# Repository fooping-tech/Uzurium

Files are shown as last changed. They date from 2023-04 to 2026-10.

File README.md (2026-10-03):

# Uzurium

Uzurium は、エモーショナルな渦を生成するオープンソースの装置です。
音楽・演劇・アートなどの表現活動において、独創的な演出を可能にすることを目指しています。

Uzurium_pic

## 特徴

- **オープンソース**：ソフトウェア・ハードウェアともに公開しており、自由に改良・再利用できます。
- **多彩な表現**：モータの回転と LED の光を組み合わせて、独自の渦を生み出せます。
- **作りやすさ**：シンプルな構造で、部品も入手しやすくなっています。
- **協調制御**：ESP-NOW で無線接続し、複数台の Uzurium を連携させられます。

## しくみ

DC モータで磁石を回し、瓶の中の回転子へ磁力で動力を伝えて渦を発生させます。
電源は、据え置きに便利な USB と、持ち運びに便利な電池の両方に対応しています。

内部構造

### 主な構成部品

- M5Atom（または M5Stamp）
- 制御基板（モータドライバ・昇圧電源・フォトリフレクタ・LED 18 灯を搭載）
- FA-130 モータ
- ネオジム磁石・回転子・瓶
- 電池ボックス
- 専用ケース（3D プリント）

## リポジトリ構成

```
Uzurium/
├── src/                      ファームウェア（Arduino スケッチ）
│   ├── Uzurium/              本体用（M5Atom）
│   ├── UzuriumController/    コントローラ用（M5Stack Core2）
│   └── UzuriumMaster/        マスター用（M5Stack Core2）
├── hardware/
│   ├── pcb/                  基板設計データ
│   │   ├── UzuriumCircuit_2/       最新基板：Gerber・BOM・レイアウト図・DXF
│   │   └── UzuriumBoard_v0.0.0/    初代基板：回路図・変更箇所
│   └── stl/                  3D プリント用データ
│       ├── common/           共通部品（プロペラ・モータブラケット等）
│       ├── case/             専用ケース
│       └── devkit/           DevKit 用部品
└── docs/
    └── BuildManual.md        DevKit 組立説明書
```

## ハードウェア

| 内容 | 場所 |
|---|---|
| 基板（最新） | [hardware/pcb/UzuriumCircuit_2](hardware/pcb/UzuriumCircuit_2) — Gerber・部品表・レイアウト図・外形 DXF |
| 基板（初代 v0.0.0） | [hardware/pcb/UzuriumBoard_v0.0.0](hardware/pcb/UzuriumBoard_v0.0.0) — 回路図と実装時の定数変更 |
| 3D プリント部品 | [hardware/stl](hardware/stl) |

## ビルドガイド

組み立て方法は [DevKit 組立説明書](docs/BuildManual.md) を参照してください。
はんだ付けなど、基本的な電子工作のスキルが必要です。

## ファームウェアの書き込み

Arduino IDE と M5Stack のボードマネージャがインストール済みであることを前提とします。

### 1. プロジェクトのダウンロード

```sh
git clone https://github.com/fooping-tech/Uzurium.git
```

または GitHub の「Code → Download ZIP」からダウンロードしてください。

### 2. ライブラリのインストール

Arduino IDE のライブラリマネージャから、使用するスケッチに応じて以下をインストールしてください。

| スケッチ | 対象デバイス | 必要なライブラリ |
|---|---|---|
| `src/Uzurium` | M5Atom | M5Atom, FastLED, arduinoFFT |
| `src/UzuriumController` | M5Stack Core2 | M5Unified, arduinoFFT, ArduinoTrace |
| `src/UzuriumMaster` | M5Stack Core2 | M5Core2 |

### 3. 書き込み

Uzurium 本体の場合は `src/Uzurium/Uzurium.ino` を Arduino IDE で開き、M5Atom に書き込みます。
コントローラ・マスターも同様に、各フォルダの `.ino` ファイルを開いて書き込んでください。

## ライセンス

Uzurium は MIT ライセンスで公開しています。詳細は [LICENSE](LICENSE) を参照してください。

## Third-party software

This firmware uses arduinoFFT.

- arduinoFFT version: 1.6.2
- License: GNU GPL v3
- Source: https://github.com/kosme/arduinoFFT

The source code corresponding to the firmware distributed with the device
is available in this repository.

## 作者

Uzurium は [@FoopingTech](https://github.com/fooping-tech) が開発しています。
ご意見・ご要望は Issues または Pull Request でお寄せください。

## 貢献方法

バグ報告、ドキュメントやコードの改善、新機能の追加など、Uzurium の改善・発展へのご協力を歓迎します。
詳細は [CONTRIBUTING.md](CONTRIBUTING.md) を参照してください。

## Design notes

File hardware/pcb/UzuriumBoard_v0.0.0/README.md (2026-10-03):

# Uzurium Board v0.0.0

初代 Uzurium 基板の回路図です。

- [SCH_UzuriumCircuit_2023-08-30.pdf](SCH_UzuriumCircuit_2023-08-30.pdf)

## 回路図からの変更箇所

v0.0.0 基板では、回路図の定数から以下の部品を変更して実装してください。

### フォトセンサ感度変更
- RPH1: 220Ω → 110Ω
- RPH2: 1kΩ → 10kΩ

### 昇圧電源 FB 電圧変更
- RP1: 1.37kΩ → 10kΩ
- RP2: 10kΩ → 1.37kΩ

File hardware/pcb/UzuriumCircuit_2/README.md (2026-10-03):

# UzuriumCircuit_2

Uzurium 制御基板（UzuriumCircuit_2）の設計データです。EasyEDA で設計しています（2026-10-04 出力）。

## ファイル

| ファイル | 内容 |
|---|---|
| [Gerber_PCB_UzuriumCircuit_2_2026-10-04.zip](Gerber_PCB_UzuriumCircuit_2_2026-10-04.zip) | 基板製造用 Gerber / ドリルデータ |
| [BOM_UzuriumCircuit_UzuriumCircuit_2026-10-04.csv](BOM_UzuriumCircuit_UzuriumCircuit_2026-10-04.csv) | 部品表（UTF-16・タブ区切り、EasyEDA 出力形式） |
| [PCB_PCB_UzuriumCircuit_2_2026-10-04.pdf](PCB_PCB_UzuriumCircuit_2_2026-10-04.pdf) | 基板レイアウト図 |
| [DXF_PCB_UzuriumCircuit_2_2026-10-04.dxf](DXF_PCB_UzuriumCircuit_2_2026-10-04.dxf) | 基板外形 DXF（ケース設計用） |

## 基板の発注

Gerber の zip ファイルをそのまま JLCPCB などの基板製造サービスにアップロードしてください。
発注手順は [EasyEDA のドキュメント](https://prodocs.easyeda.com/en/pcb/order-order-pcb/index.html) を参照してください。

## 部品表（BOM）

LCSC 列は LCSC / JLCPCB の部品番号です。

| No. | 数量 | 部品 | リファレンス | フットプリント | メーカー型番 | メーカー | LCSC |
|---|---|---|---|---|---|---|---|
| 1 | 9 | 100nF | C13, CA1, CM1, CM2, CM3, CM5, CM6, CPH1, CS1 | C0603 | CL10B104KC8NNNC | SAMSUNG(三星) | C15725 |
| 2 | 1 | 270uF | CM4 | CAP-SMD_BD10.0-L10.3-W10.3-FD | EEHZA1V271P | PANASONIC(松下) | C79124 |
| 3 | 1 | B3B-XH-AM-(LF)(SN) | CNA1 | CONN-TH_3P-P2.50_B3B-XH-AM-LF-SN | B3B-XH-AM(LF)(SN) | JST | C161870 |
| 4 | 2 | B2B-XH-A-M_C2858045 | CNB1, CNM1 | CONN-TH_2P-P2.50_JST_B2B-XH-A-M_C2858045 | B2B-XH-A-M | JST | C2858045 |
| 5 | 1 | M5 ATOM PCB Connector | CNM5 | M5ATOM |  |  | M5-ATOM-PCB-CONN |
| 6 | 2 | 22uF | CP1, CP2 | 0805 | GRM21BR60J226ME39L | MuRata | C77071 |
| 7 | 1 | B0520LW | DP1 | SOD-123 | B0520LW | STARSEA | C89640 |
| 8 | 1 | 1SMA4734A_C438355 | DP2 | SMA_L4.3-W2.5-LS5.0-RD | 1SMA4734A | 晶导微电子 | C438355 |
| 9 | 1 | DRV8839DSSR | ICM1 | WSON-12_L3.0-W2.0-P0.50-BL-EP | DRV8839DSSR | TI(德州仪器) | C128627 |
| 10 | 1 | SX1308 | ICP1 | SOT-23-6 | SX1308 | SX | C78162 |
| 11 | 1 | LBR-127HLD | ICPH1 | LBR-127HLD | RPR-220 | ROHM(罗姆) | C21062 |
| 12 | 1 | TC7S14FU,LF | ICPH2 | SOT-353-5_L2.0-W2.1-P0.65-BR | TC7S14FU,LF | TOSHIBA(东芝) | C7032 |
| 13 | 18 | WS2812B-XF02/W | LED1〜LED18 | LED-SMD_4P-L5.0-W5.0-TL | WS2812B-XF02/W | worldsemi | C4154882 |
| 14 | 1 | 4.7uH | LP1 | 5040 | SWPA5040S4R7MT | Sunlord | C48496 |
| 15 | 8 | 1kΩ | RM1, RM2, RM3, RPH2, RPH3, RPH4, RS1, RS2 | R0603 | WR06X102JTL | Walsin(华新科) | C384295 |
| 16 | 1 | 1.37kΩ | RP1 | R0805 | RTT051371FTP | RALEC(旺诠) | C103980 |
| 17 | 1 | 10kΩ | RP2 | R0805 | RTT051002FTP | RALEC(旺诠) | C103904 |
| 18 | 1 | 220 | RPH1 | R0603 | RC0603JR-07220RL | YAGEO(国巨) | C114683 |
| 19 | 1 | SK-22F03-G060 | SWB1 | SW-TH_G-SWITCH_SK-22F03-G060 | SK-22F03-G060 | G-Switch(品赞) | C2848866 |
| 20 | 1 | PS-5850DHA-3PNA | SWS1 | SW-TH_G-SWITCH_PS-585XX | PS-5850DHA-3PNA | G-Switch(品赞) | C5155592 |
| 21 | 3 | 5004 | TP33, TP50, TPBAT1 | TEST-TH_BD2.54-P1.39 | 5004 | Keystone | C2906762 |
| 22 | 1 | 5001 | TPGND1 | TEST-TH_BD2.54-P1.39 | 5001 | Keystone | C238122 |

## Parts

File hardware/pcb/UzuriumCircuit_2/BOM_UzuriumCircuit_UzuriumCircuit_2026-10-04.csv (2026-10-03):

No. | Quantity | Comment | Designator | Footprint | Value | Manufacturer Part | Manufacturer | Supplier Part | Supplier
1 | 9 | 100nF | C13,CA1,CM1,CM2,CM3,CM5,CM6,CPH1,CS1 | C0603 |  | CL10B104KC8NNNC | SAMSUNG(三星) | C15725 | LCSC
2 | 1 | 270uF | CM4 | CAP-SMD_BD10.0-L10.3-W10.3-FD |  | EEHZA1V271P | PANASONIC(松下) | C79124 | LCSC
3 | 1 | B3B-XH-AM-(LF)(SN) | CNA1 | CONN-TH_3P-P2.50_B3B-XH-AM-LF-SN |  | B3B-XH-AM(LF)(SN) | JST | C161870 | LCSC
4 | 2 | B2B-XH-A-M_C2858045 | CNB1,CNM1 | CONN-TH_2P-P2.50_JST_B2B-XH-A-M_C2858045 |  | B2B-XH-A-M | JST | C2858045 | LCSC
5 | 1 | M5 ATOM PCB Connector | CNM5 | M5ATOM |  |  |  | M5-ATOM-PCB-CONN
6 | 2 | 22uF | CP1,CP2 | 0805 |  | GRM21BR60J226ME39L | MuRata | C77071 | LCSC
7 | 1 | B0520LW | DP1 | SOD-123 |  | B0520LW | STARSEA | C89640 | LCSC
8 | 1 | 1SMA4734A_C438355 | DP2 | SMA_L4.3-W2.5-LS5.0-RD |  | 1SMA4734A | 晶导微电子 | C438355 | LCSC
9 | 1 | DRV8839DSSR | ICM1 | WSON-12_L3.0-W2.0-P0.50-BL-EP |  | DRV8839DSSR | TI(德州仪器) | C128627 | LCSC
10 | 1 | SX1308 | ICP1 | SOT-23-6 |  | SX1308 | SX | C78162 | LCSC
11 | 1 | LBR-127HLD | ICPH1 | LBR-127HLD |  | RPR-220 | ROHM(罗姆) | C21062 | LCSC
12 | 1 | TC7S14FU,LF | ICPH2 | SOT-353-5_L2.0-W2.1-P0.65-BR |  | TC7S14FU,LF | TOSHIBA(东芝) | C7032 | LCSC
13 | 18 | WS2812B-XF02/W | LED1,LED2,LED3,LED4,LED5,LED6,LED7,LED8,LED9,LED10,LED11,LED12,LED13,LED14,LED15,LED16,LED17,LED18 | LED-SMD_4P-L5.0-W5.0-TL |  | WS2812B-XF02/W | worldsemi | C4154882 | LCSC
14 | 1 | 4.7uH | LP1 | 5040 |  | SWPA5040S4R7MT | Sunlord | C48496 | LCSC
15 | 8 | 1kΩ | RM1,RM2,RM3,RPH2,RPH3,RPH4,RS1,RS2 | R0603 |  | WR06X102JTL | Walsin(华新科) | C384295 | LCSC
16 | 1 | 1.37kΩ | RP1 | R0805 |  | RTT051371FTP | RALEC(旺诠) | C103980 | LCSC
17 | 1 | 10kΩ | RP2 | R0805 |  | RTT051002FTP | RALEC(旺诠) | C103904 | LCSC
18 | 1 | 220 | RPH1 | R0603 |  | RC0603JR-07220RL | YAGEO(国巨) | C114683 | LCSC
19 | 1 | SK-22F03-G060 | SWB1 | SW-TH_G-SWITCH_SK-22F03-G060 |  | SK-22F03-G060 | G-Switch(品赞) | C2848866 | LCSC
20 | 1 | PS-5850DHA-3PNA | SWS1 | SW-TH_G-SWITCH_PS-585XX |  | PS-5850DHA-3PNA | G-Switch(品赞) | C5155592 | LCSC
21 | 3 | 5004 | TP33,TP50,TPBAT1 | TEST-TH_BD2.54-P1.39 |  | 5004 | Keystone | C2906762 | LCSC
22 | 1 | 5001 | TPGND1 | TEST-TH_BD2.54-P1.39 |  | 5001 | Keystone | C238122 | LCSC

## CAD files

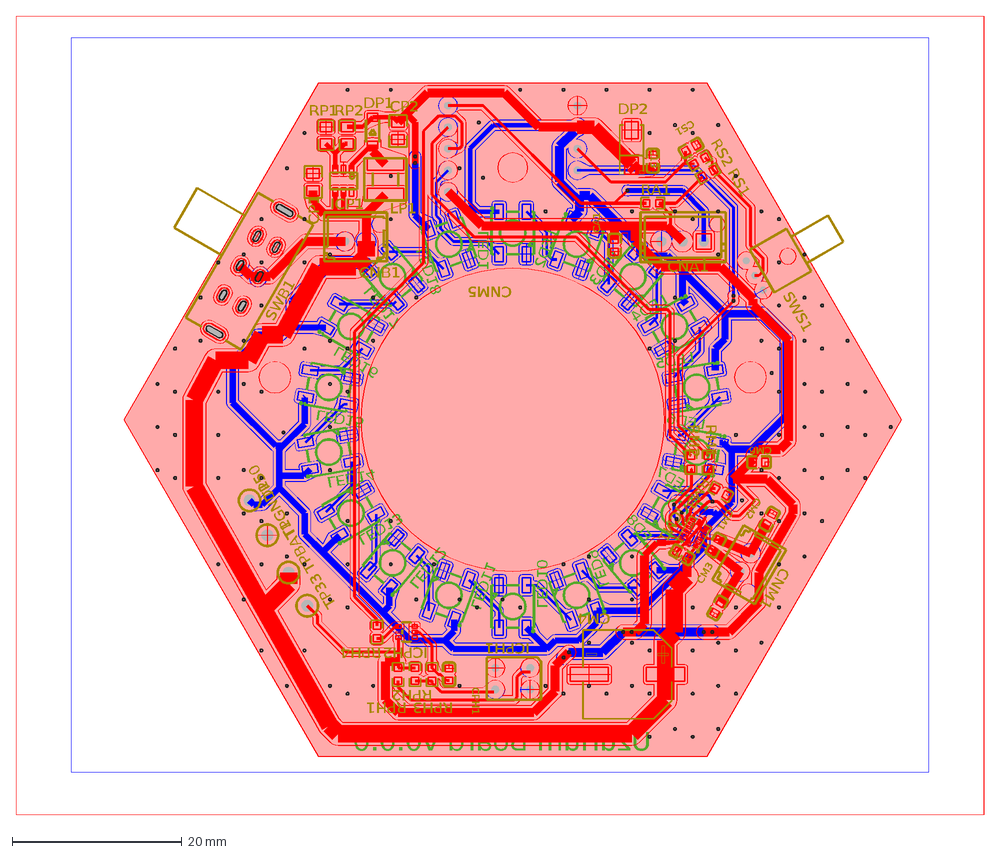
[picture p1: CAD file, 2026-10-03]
hardware/pcb/UzuriumCircuit_2/DXF_PCB_UzuriumCircuit_2_2026-10-04.dxf
Uzurium Board v0.0.0
LED1
LED2
LED3
LED4
LED5
LED6
LED7
LED8
LED9
LED10
LED11
LED12
LED13
LED14
LED15
LED16
LED17
LED18
TPGND1
TP33
TP50
CM4
CNA1
CNB1
CNM1
CNM5
CP1
CP2
DP1
DP2
ICM1
ICP1
ICPH1
ICPH2
LP1
RA1
RM1
RM2
RM3
RP1
RP2
RPH1
RPH2
RPH3
RPH4
RS1
RS2
SWB1
SWS1
TPBAT1
CM2
CM3
CM5
CM6
CPH1
CA1
CS1
CM1
C13

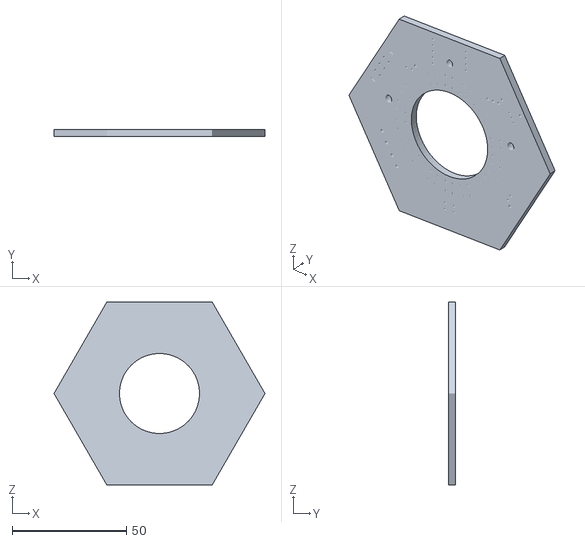
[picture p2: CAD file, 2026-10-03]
hardware/stl/case/cap.stl
92.3 x 2.90 x 80.0

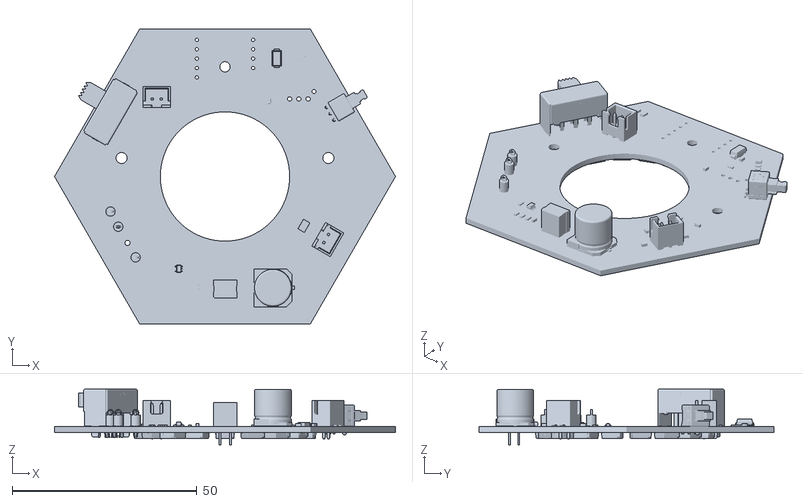
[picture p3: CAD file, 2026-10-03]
hardware/stl/common/3D_PCB_UzuriumCircuit_v.0.0.0.stl
92.3 x 80.0 x 15.1

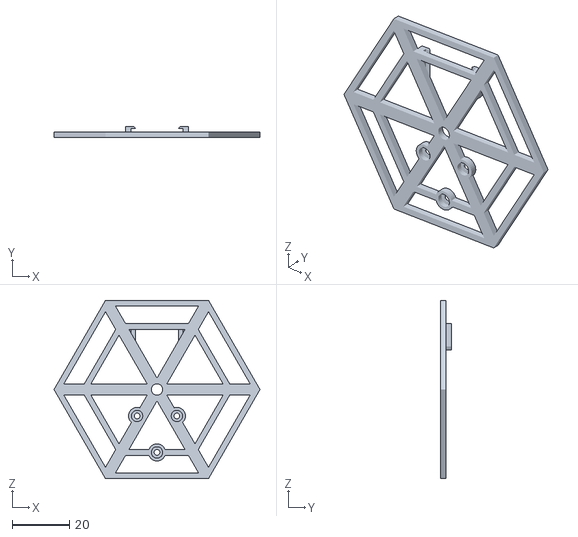
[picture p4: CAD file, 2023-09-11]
hardware/stl/devkit/bottom.stl
72.0 x 4.00 x 62.4

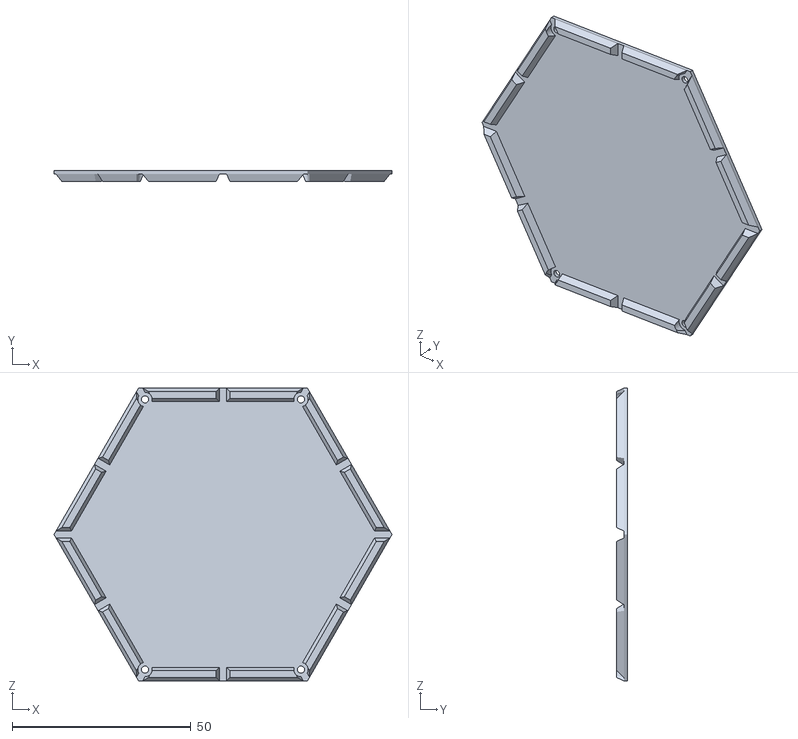
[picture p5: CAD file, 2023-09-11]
hardware/stl/case/bottom.stl
94.7 x 3.00 x 82.0

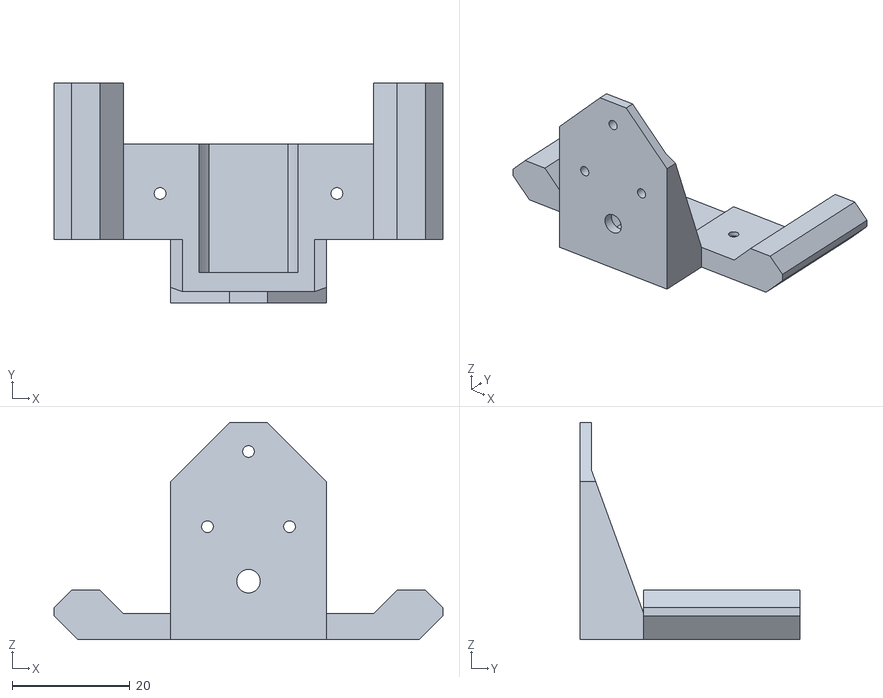
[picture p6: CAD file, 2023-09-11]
hardware/stl/common/MotorBraket.stl
66.0 x 37.4 x 36.8

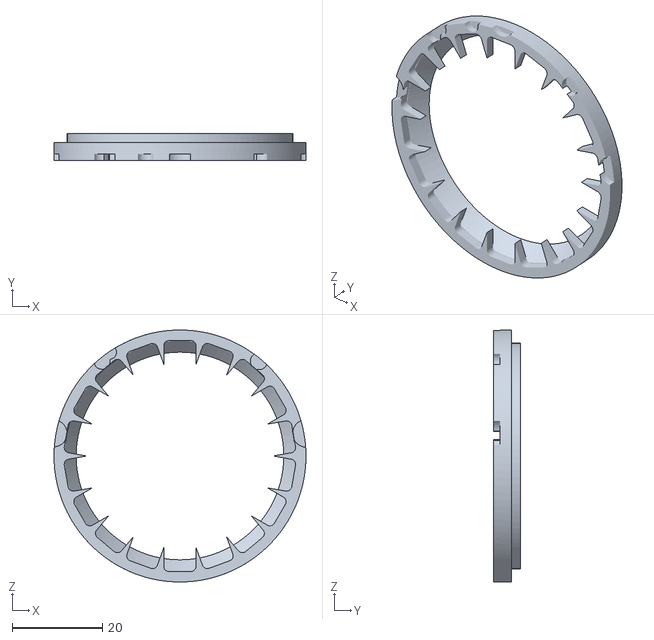
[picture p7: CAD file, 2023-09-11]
hardware/stl/devkit/CAP2.stl
55.8 x 5.90 x 55.8

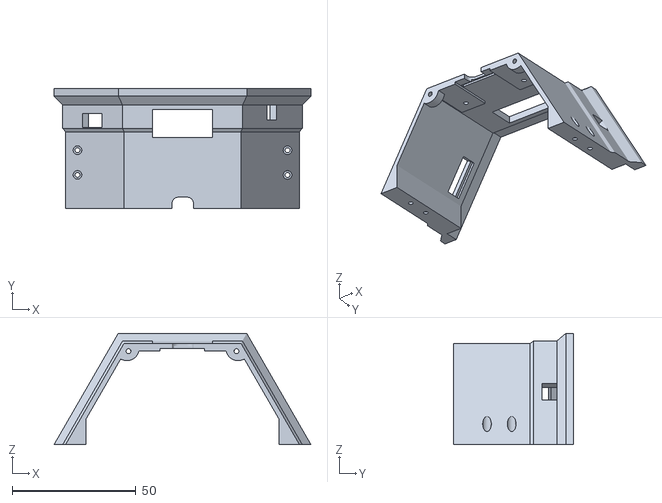
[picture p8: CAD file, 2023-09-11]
hardware/stl/case/CASE_ushiro.stl
104.0 x 48.4 x 45.0

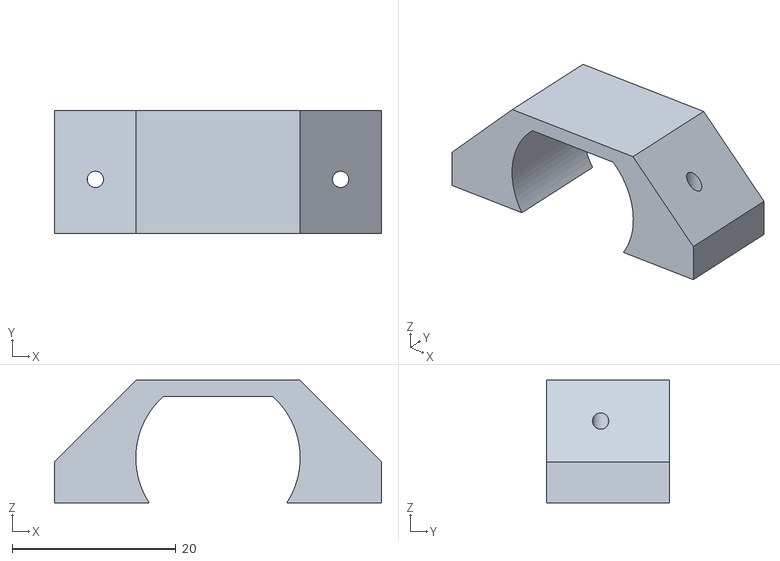
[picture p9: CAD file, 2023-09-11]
hardware/stl/common/MotorCover.stl
40.0 x 15.0 x 15.0

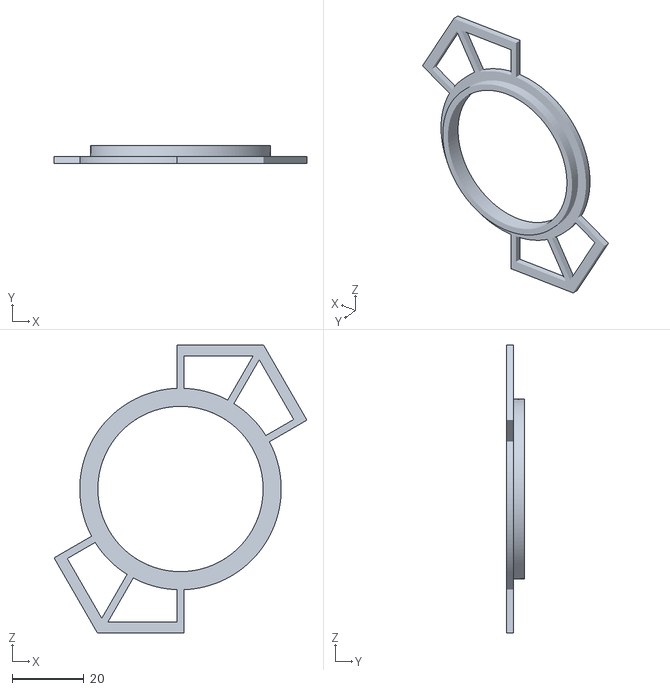
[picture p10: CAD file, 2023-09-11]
hardware/stl/case/top.stl
70.4 x 5.00 x 80.2

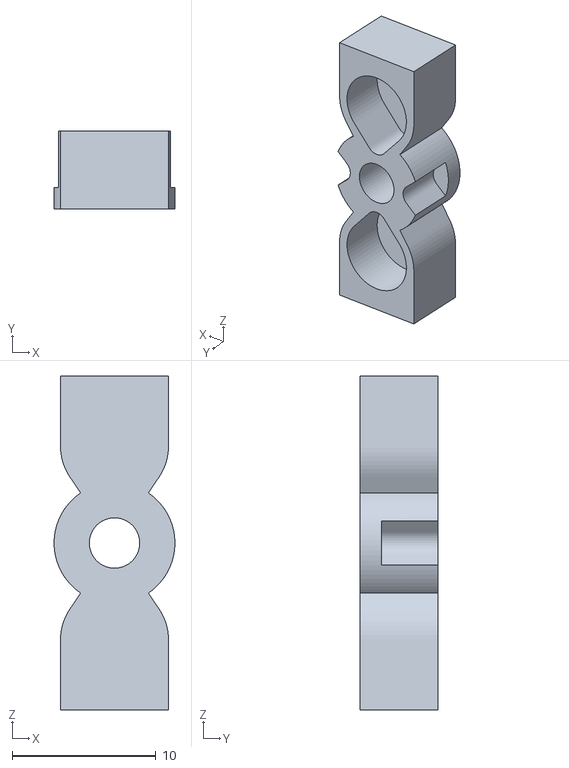
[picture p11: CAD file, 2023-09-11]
hardware/stl/common/propeller.stl
8.39 x 5.40 x 23.2

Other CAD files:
hardware/stl/case/CASE_mae.stl

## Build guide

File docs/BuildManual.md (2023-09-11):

# Uzurium DevKit 組立説明書

## 完成イメージ





## 部品リスト

部品一覧

| No. | 部品名称 | 個数 | イメージ |
|---|---|---|---|
| 1 | プロペラ・ネオジム磁石x2・反射シール | 1set | スクリーンショット 2023-09-09 0 05 23 |
| 2 | モータワイヤ | 1 |スクリーンショット 2023-09-09 0 06 24|
| 3 | モータ | 1 |スクリーンショット 2023-09-09 0 06 35|
| 4 | モータカバー | 1 |スクリーンショット 2023-09-09 0 06 44|
| 5 | モータステー | 1 | スクリーンショット 2023-09-09 0 06 55|
| 6 | ネジ | 1set | スクリーンショット 2023-09-09 0 07 06|
| 7 | NEO PIXEL LED | 1set | スクリーンショット 2023-09-09 0 07 15|
| 8 | USB充電基板 | 1 |スクリーンショット 2023-09-09 0 12 56|
| 9 | 電源ワイヤ | 1 |スクリーンショット 2023-09-09 0 13 59|
| 10 | ピンヘッダ | 1 |スクリーンショット 2023-09-09 0 15 52|
| 11 | フォトセンサ | 1 |スクリーンショット 2023-09-09 0 16 08|
| 12 | Uzurium基板 | 1 |スクリーンショット 2023-09-09 0 16 21|
| 13 | トップカバー | 1 |スクリーンショット 2023-09-09 0 16 40|
| 14 | ボトムプレート | 1 |スクリーンショット 2023-09-09 0 16 56|
| 15 | 回転子 | 1 |スクリーンショット 2023-09-09 0 17 19|
| 16 | 拡張キット | 1set |スクリーンショット 2023-09-09 0 17 35|

## 必要なもの
- プラスドライバー
- ラジオペンチ
- はんだごて・はんだ

## 組み立て方
### モータとモータワイヤを半田付けする



### モータをモータカバーとモータステー、M2ネジ6mmx2で固定する


### プロペラに反射シールを貼る
### プロペラにネオジム磁石を押し込む(硬い場合はラジオペンチで挟み押し込む)
### モータ付属のゴムチューブを5mm程度にカットしプロペラの中央穴に裏面から差し込む


### プロペラをモータの軸に差し込む


### Uzurium基板にピンヘッダを半田付けする


### Uzurium基板にフォトセンサを半田付けする
RPH1を100Ωへ変更する


### Uzurium基板にNEO PIXEL LEDを半田付けする


### USB充電基板に電源ワイヤを半田付けする


### ボトムプレートにUSB充電基板を固定する


### モータステーとボトムプレートをM2ネジ4mm x3で固定する


### Uzurium基板とモータステーをM2ネジ6mm x2で固定する


### トッププレートを被せる


### 電源ワイヤをUzurium基板のCNB1コネクタに差し込む


### モータワイヤをUzurium基板のCNM1コネクタに差し込む


### M5ATOMをピンヘッダに差し込む

### Uzurium DevKit完成！

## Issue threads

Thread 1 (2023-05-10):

時報機能のための基本的な関数の提供について

fooping-tech, 2023-05-10:
## 概要
Uzuriumには、時報機能が必要です。この機能を組み込むために、開発者が利用できる基本的な関数を提供したいと考えています。

## 要件
- 開発者は、現在の時刻を取得するための関数を利用できる必要があります。
- 開発者は、時刻を設定するためにインターネット関数を利用できる必要があります。
- 開発者は、タイマーを開始し、経過時間を取得するための関数を利用できる必要があります。
- 開発者は、タイマーを停止するための関数を利用できる必要があります。
- 開発者は、現在の日付を取得するための関数を利用できる必要があります。
- 開発者は、NTPサーバーからの現在時刻取得機能を利用できる必要があります

fooping-tech, 2023-12-05:
ntpブランチにて実装中
https://github.com/fooping-tech/Uzurium/tree/feature/ntp

fooping-tech, 2023-12-05:
mainにマージ

Closed 2023-12-05.

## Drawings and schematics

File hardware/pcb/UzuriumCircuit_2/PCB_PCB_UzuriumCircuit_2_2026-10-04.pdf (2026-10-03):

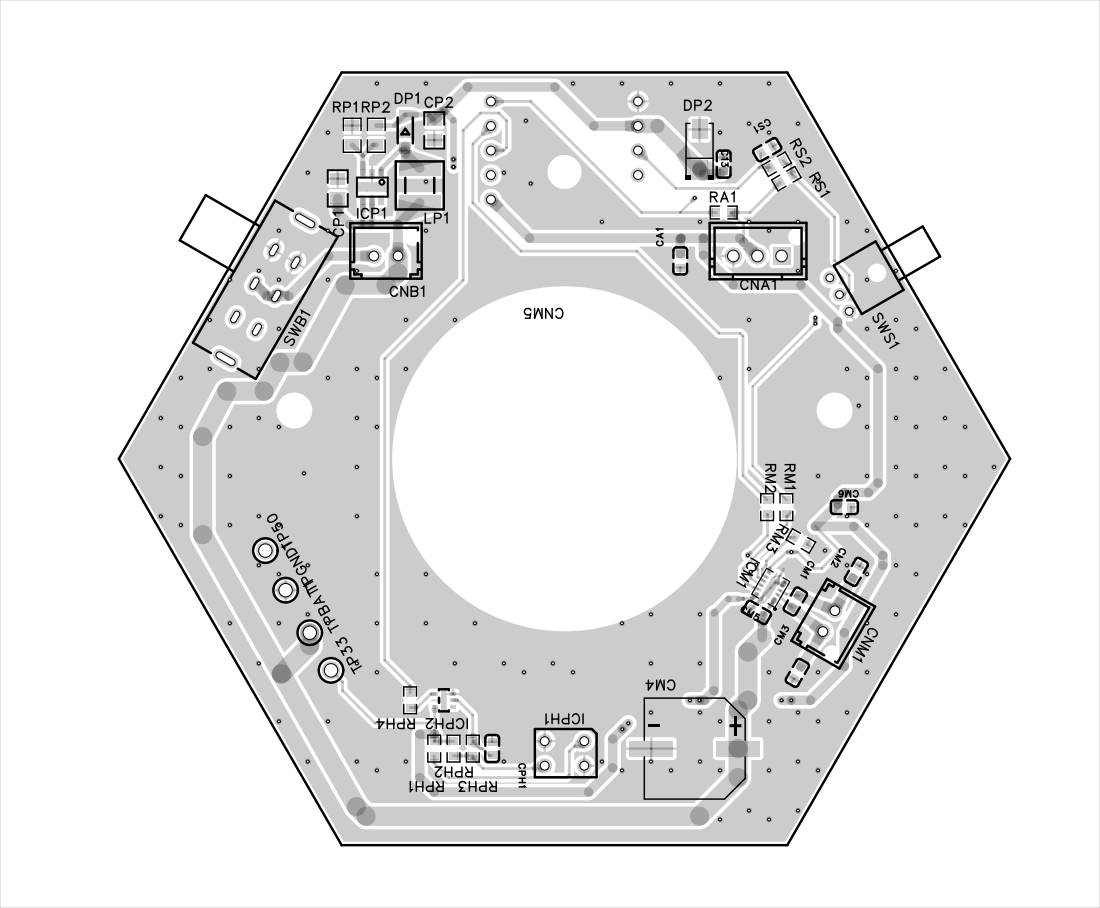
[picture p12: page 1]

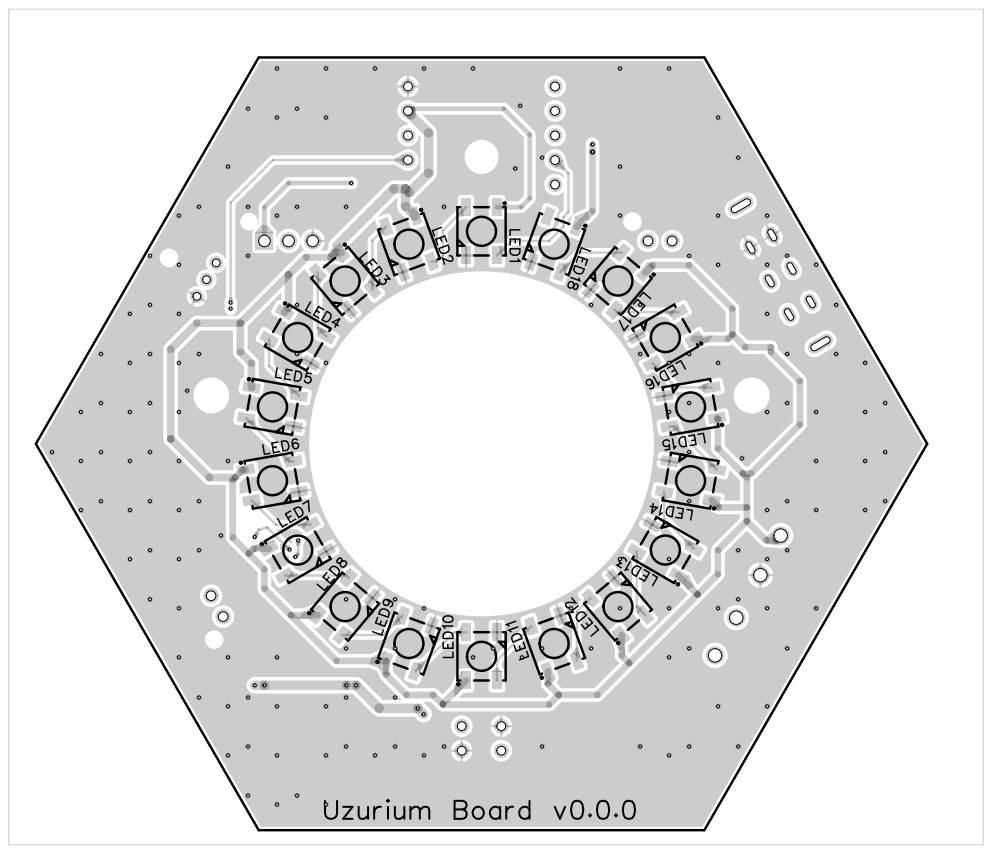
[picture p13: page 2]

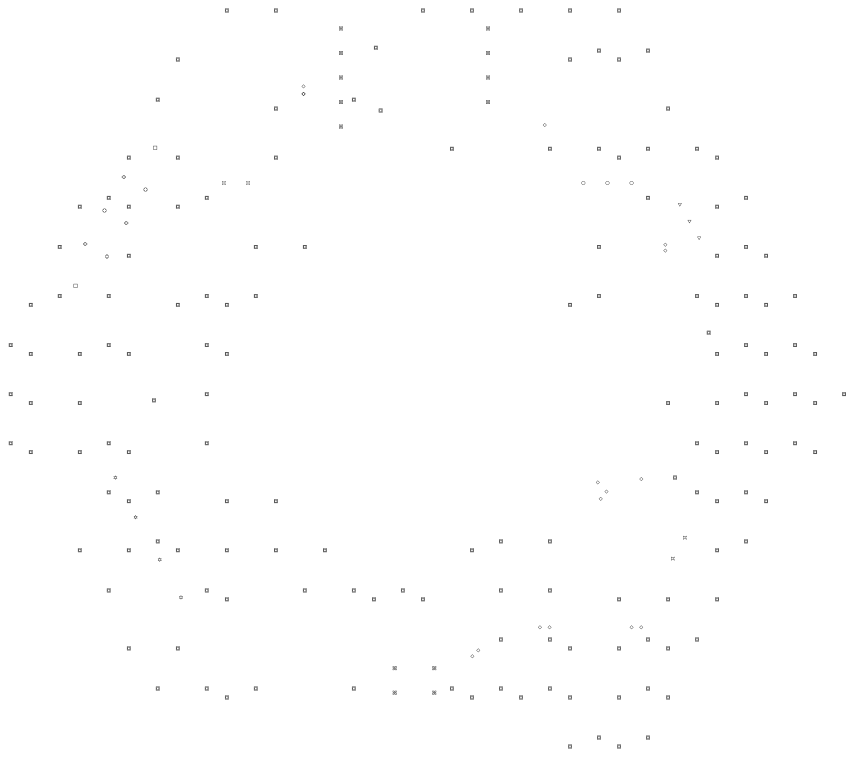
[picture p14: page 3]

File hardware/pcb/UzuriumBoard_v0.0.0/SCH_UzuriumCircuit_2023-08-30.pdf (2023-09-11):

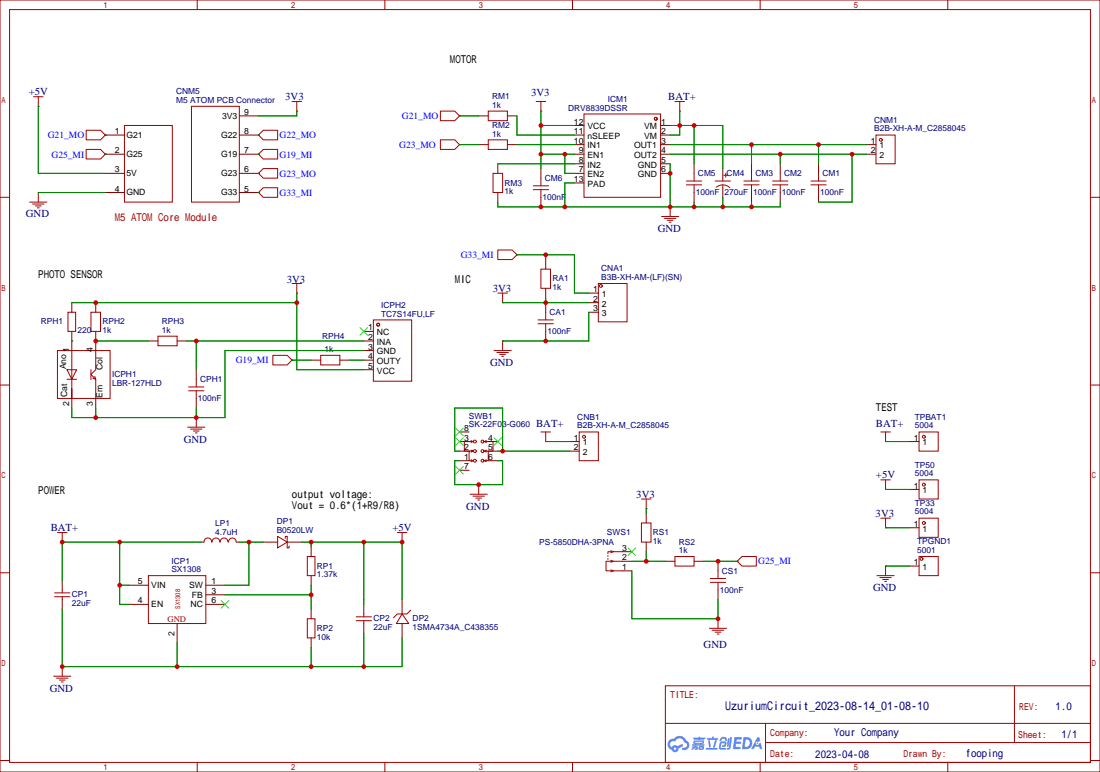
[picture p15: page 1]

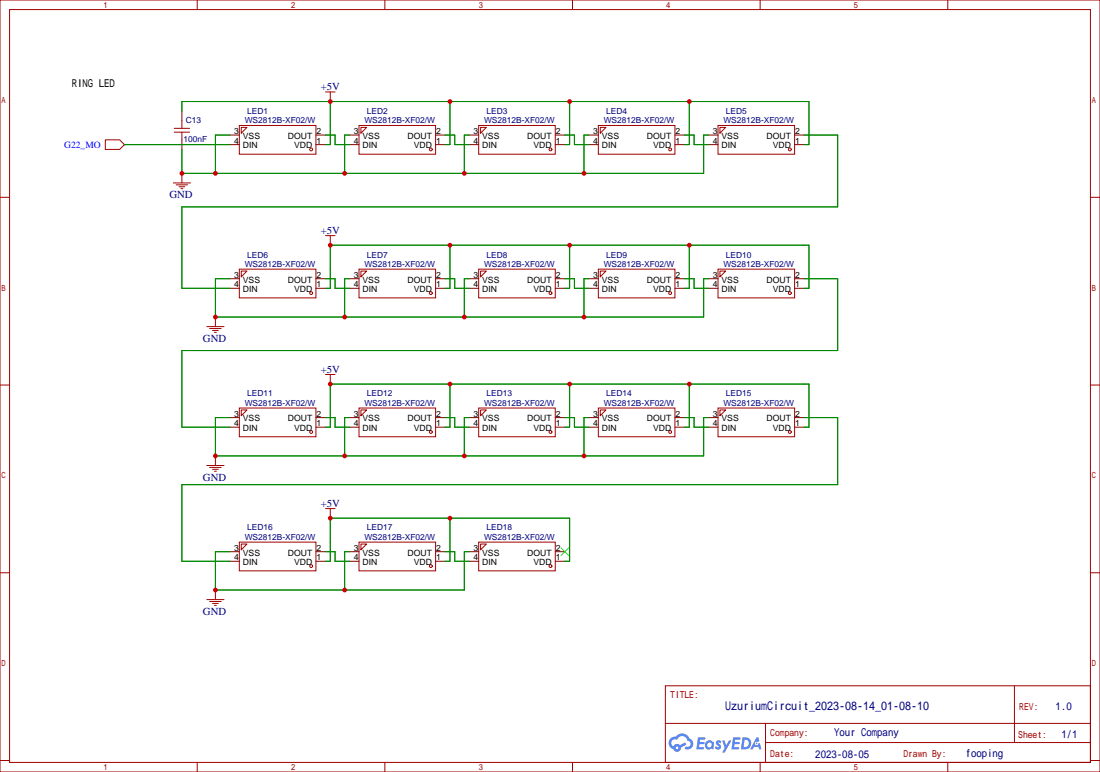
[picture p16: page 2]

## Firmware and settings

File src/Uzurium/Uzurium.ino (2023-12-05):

#include "./configuration.h"
#if __has_include("Setting.h")
#include "./Setting.h"
#else
#define WIFI_SSID "your_ssid"
#define WIFI_PASS "your_password"
#endif
DCMPWM motor = DCMPWM();
RINGLED led = RINGLED();
PHOTO photo = PHOTO();
SW switch1 = SW(SW_PIN,INPUT);
SW switch2 = SW(TEST_SW_PIN,INPUT_PULLUP);

// モードオブジェクトのポインタ
MODE *currentMode;

// WiFiの接続処理
void initWiFi() {
  WiFi.mode(WIFI_STA);
  Serial.print("\nConnecting to " WIFI_SSID);
  WiFi.begin(WIFI_SSID, WIFI_PASS);     // WiFiに接続
  int i = 1;
  while (WiFi.status() != WL_CONNECTED) { // WiFiが繋がるまでループ
    if (i > 20) {                       // 10秒のタイムアウト
      Serial.println("\n========== WiFi connecting timeout! ==========\n");
      //ESP.restart();                    // リセット
      break;
    }
    delay(500);                         // 500ミリ秒待つ
    Serial.print(".");                  // ログに「.」を表示
    i++;
  }
  Serial.println("\nWiFi connected");   // ログに「WiFi connected」を表示
  Serial.print("IP address: ");         // ログにIPアドレスを表示
  Serial.println(WiFi.localIP());
}

void setup() {
  //M5 INITIAL

  M5.begin(true, false, true); 
  //MOTOR INITIAL
  motor.setup(CHANNEL,MOTOR_PIN);
  photo.setup(PHOTO_PIN);
  
  //MOTOR SLEEP
  // pinMode(21, OUTPUT);
  // digitalWrite(21, HIGH);

  //LED_INITIAL
  led.setup(LED_PIN);//led setup (led_num)

  //ESP-NOW INITIAL
  ESPNOW_setup();
  initWiFi();                           // WiFiの接続処理
  // NTPの初期化
  configTzTime("JST-9", "ntp.nict.jp"); 
  //timeInfo.tm_year + 1900 //timeInfo.tm_mon + 1 //timeInfo.tm_mday //timeInfo.tm_hour //timeInfo.tm_min //timeInfo.tm_sec

  //初期モードにセット
  if(switch2.check_a()==1){
    currentMode = new StopMode(&photo,&motor,&led);
  }
  else{
    currentMode = new TestMode(&photo,&motor,&led);
  }
  //Core0でタスク起動
  xTaskCreatePinnedToCore(
    Uzurium_Task        // タスク関数へのポインタ。無限ループで終了しないよう関数を指定します
    ,  "TaskMotion"   // タスクの説明用名前。重複しても動きますがデバッグ用途。最大16文字まで
    ,  4096  //スタックサイズ(Byte)
    ,  NULL //作成タスクのパラメータのポインタ
    ,  2  // Priority, with 3 (configMAX_PRIORITIES - 1) being the highest, and 0 being the lowest..  优先级，3 (configMAX_PRIORITIES - 1) 最高，0 最低。
    ,  NULL //作成タスクのHandleへのポインタ
    ,  0);  //利用するCPUコア(0-1)
}

void Uzurium_Task(void *pvParameters){
  while(1){
    Uzurium_main();
    delay(1);
  }
}

void Uzurium_Ntp(){
  struct tm timeInfo;
  getLocalTime(&timeInfo);
  if(timeInfo.tm_sec == 0 && currentMode->name == "StopMode"){
    delete currentMode;
    currentMode = new TimerMode(&photo,&motor,&led);
  }
}

void Uzurium_CheckSW(){
  //スイッチ(モーメンタリ)
  int sw = switch1.check_m();
  //スイッチ(オルタネート)
  int sw2= switch2.check_a();
  //前回値からの変更有無
  bool sw2st = switch2.check_change();
  //TEST_SWが前回値から変更されていたらsw2の論理にあわせたモードへ変更
  if(sw2st){
      if(sw2==0){
        delete currentMode;
        currentMode = new TestMode(&photo,&motor,&led);
      }
      else{
        delete currentMode;
        currentMode = new StopMode(&photo,&motor,&led);
      }
  }

  if(sw2==1){//オルタネートSW = OFF
    // ダブル:3 ,長押し:2,短押し:1,押していない:0
    if(sw==1){
      if(currentMode->name != "StopMode"){
        delete currentMode;
        currentMode = new StopMode(&photo,&motor,&led);
      }else{
        delete currentMode;
        currentMode = new ADinputMode(&photo,&motor,&led);
      }
    }
    if(sw==2){
        delete currentMode;
        currentMode = new FeedBackMode(&photo,&motor,&led);
    }
    if(sw==3){
        delete currentMode;
        currentMode = new TimerMode(&photo,&motor,&led);
    }



    //M5AtomSWプッシュ時の動作
    if(M5.Btn.wasPressed()){
        if(currentMode->name=="StopMode"){
          delete currentMode;
          currentMode = new ADinputMode(&photo,&motor,&led);
        }else 
        if(currentMode->name=="ADinputMode"){
          delete currentMode;
          currentMode = new FeedBackMode(&photo,&motor,&led);
        }else 
        if(currentMode->name=="FeedBackMode"){
          delete currentMode;
          currentMode = new TimerMode(&photo,&motor,&led);
        }else
        if(currentMode->name=="TimerMode"){
          delete currentMode;
          currentMode = new StopMode(&photo,&motor,&led);
        }

    }
 
  }else{//オルタネートSW = ON
    // ダブル:3 ,長押し:2,短押し:1,押していない:0
    if(sw==1){
      if(currentMode->name != "TestMode"){
        delete currentMode;
        currentMode = new TestMode(&photo,&motor,&led);
      }else{
        delete currentMode;
        currentMode = new ADInspectionMode(&photo,&motor,&led);
      }
    }
    if(sw==2){
        delete currentMode;
        currentMode = new PhotoReflectorInspectionMode(&photo,&motor,&led);
    }
    if(sw==3){
        delete currentMode;
        currentMode = new LedInspectionMode(&photo,&motor,&led);
      
    }

    if(M5.Btn.wasPressed()){
        if(currentMode->name=="TestMode"){
          delete currentMode;
          currentMode = new ADInspectionMode(&photo,&motor,&led);
        }else 
        if(currentMode->name=="ADInspectionMode"){
          delete currentMode;
          currentMode = new PhotoReflectorInspectionMode(&photo,&motor,&led);
        }else 
        if(currentMode->name=="PhotoReflectorInspectionMode"){
          delete currentMode;
          currentMode = new TestMode(&photo,&motor,&led);
        }
    }
  }
}

void Uzurium_main(){

// 現在のモードのmainloop()を呼び出す
  currentMode->mainloop();
  currentMode->SetAdValue(FFT_CheckADvalue());

  //現在の実行モードが非アクティブになった場合はStopModeへ入れる
  if(currentMode->active==false){
    delete currentMode;
    currentMode = new StopMode(&photo,&motor,&led);
  }
  
  //RemoteControlModeのときはESPNOW受信値をパラメータにセットする
  if(currentMode->name=="RemoteControlMode"){
    currentMode->SetParams(ESPNOW_CheckDuty(),ESPNOW_CheckHue(),ESPNOW_CheckBrightness());
  }
  //ADInspectionModeのときにUzurium_Numberを設定する
  if(currentMode->name=="ADInspectionMode"){
        Uzurium_Number =  map(FFT_CheckADvalue(),0,4095,1,18);
  }

}

void loop() {
  M5.update();
  //Analog pin読み取り
  FFT_main();
  //スイッチ状態チェック
  Uzurium_CheckSW();
  //Ntpチェック
  if(WiFi.status() == WL_CONNECTED){
    Uzurium_Ntp();
  }
}

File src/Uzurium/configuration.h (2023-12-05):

#ifndef CONFIGURATION_H
#define CONFIGURATION_H

//#include <M5Unified.h>
#include <M5Atom.h>
#include <esp_now.h>
#include <WiFi.h>
#include <Wire.h>

#include "DCMPWM.h"
#include "RINGLED.h"
#include "PHOTO.h"
#include "MODE.h"
#include "SW.h"

//motor pin setting
#define MOTOR_PIN 23

//motor PWM CH(for MotorDrive)
#define CHANNEL 2

//led pin setting
#define LED_PIN 22

//PhotoSensor pin setting
#define PHOTO_PIN 19

//Analog pin setting
#define ANALOG_PIN 33

//SW setting モーメンタリ
#define SW_PIN 25

//SW setting オルタネート
#define TEST_SW_PIN 21

int Uzurium_Number = 0;




#endif

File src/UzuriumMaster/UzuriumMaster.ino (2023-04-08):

#include <esp_now.h>
#include <WiFi.h>
#include <esp_wifi.h> // only for esp_wifi_set_channel()
#include <M5Core2.h>

// Defines gestures
Gesture swipeRight("swipe right", 160, DIR_RIGHT, 30, true);
Gesture swipeDown("swipe down", 120, DIR_DOWN, 30, true);
Gesture swipeLeft("swipe left", 160, DIR_LEFT, 30, true);
Gesture swipeUp("swipe up", 120, DIR_UP, 30, true);

// Defines the buttons. Colors in format {bg, text, outline}
ButtonColors on_clrs = {RED, WHITE, WHITE};
ButtonColors off_clrs = {BLACK, WHITE, WHITE};
Button tl(0, 0, 0, 0, false ,"top-left", off_clrs, on_clrs, TL_DATUM);
Button bl(0, 0, 0, 0, false, "bottom-left", off_clrs, on_clrs, BL_DATUM);
Button tr(0, 0, 0, 0, false, "top-right", off_clrs, on_clrs, TR_DATUM);
Button br(0, 0, 0, 0, false, "bottom-right", off_clrs, on_clrs, BR_DATUM);

// For performance measurement (Single tap on bottom-right button)
uint32_t startTime;
uint32_t times = 0;



int duty = 0;
int mode = 0;

int SQmode =0; //SequenceMode
uint32_t SQstartTime;

esp_now_peer_info_t slave;
// 送信コールバック
void OnDataSent(const uint8_t *mac_addr, esp_now_send_status_t status) {
  char macStr[18];
  snprintf(macStr, sizeof(macStr), "%02X:%02X:%02X:%02X:%02X:%02X",
           mac_addr[0], mac_addr[1], mac_addr[2], mac_addr[3], mac_addr[4], mac_addr[5]);
  // Serial.print("Last Packet Sent to: ");
  // Serial.println(macStr);
  // Serial.print("Last Packet Send Status: ");
  // Serial.println(status == ESP_NOW_SEND_SUCCESS ? "Delivery Success" : "Delivery Fail");
  // 画面にも描画
  M5.Lcd.fillScreen(BLACK);
  M5.Lcd.setCursor(0, 0);
  M5.Lcd.print("Last Packet Sent to: \n  ");
  M5.Lcd.println(macStr);
  M5.Lcd.print("Last Packet Send Status: \n  ");
  M5.Lcd.println(status == ESP_NOW_SEND_SUCCESS ? "Delivery Success" : "Delivery Fail");
}
// 受信コールバック
void OnDataRecv(const uint8_t *mac_addr, const uint8_t *data, int data_len) {
  char macStr[18];
  snprintf(macStr, sizeof(macStr), "%02X:%02X:%02X:%02X:%02X:%02X",
           mac_addr[0], mac_addr[1], mac_addr[2], mac_addr[3], mac_addr[4], mac_addr[5]);
  Serial.printf("Last Packet Recv from: %s\n", macStr);
  Serial.printf("Last Packet Recv Data(%d): ", data_len);
  for ( int i = 0 ; i < data_len ; i++ ) {
    Serial.print(data[i]);
    Serial.print(" ");
  }
  Serial.println("");
  // 画面にも描画
  M5.Lcd.fillScreen(BLACK);
  M5.Lcd.setCursor(0, 0);
  M5.Lcd.print("Last Packet Recv from: \n  ");
  M5.Lcd.println(macStr);
  M5.Lcd.printf("Last Packet Recv Data(%d): \n  ", data_len);
  for ( int i = 0 ; i < data_len ; i++ ) {
    M5.Lcd.print(data[i]);
    M5.Lcd.print(" ");
  }
  //if(data[0]==1)mode++;
  //if(mode>4)mode=0;
}

void setup() {
  M5.begin();
  M5.Lcd.fillScreen(BLACK);
  Serial.begin(115200);
//Button
  M5.Buttons.addHandler(doRotation, E_GESTURE);
  M5.Buttons.addHandler(toggleColor, E_DBLTAP);
  M5.Buttons.addHandler(eventDisplay, E_ALL - E_MOVE);
  br.addHandler(showPerformance, E_TAP);
  br.repeatDelay = 1000;
  doButtons();
  startTime = millis();
// ESP-NOW初期化
  WiFi.mode(WIFI_STA);
  WiFi.disconnect();
  if (esp_now_init() == ESP_OK) {
    Serial.println("ESPNow Init Success");
    M5.Lcd.print("ESPNow Init Success\n");
  } else {
    Serial.println("ESPNow Init Failed");
    M5.Lcd.print("ESPNow Init Failed\n");
    ESP.restart();
  }
  // マルチキャスト用Slave登録
  memset(&slave, 0, sizeof(slave));
  for (int i = 0; i < 6; ++i) {
    slave.peer_addr[i] = (uint8_t)0xff;
  }
  esp_err_t addStatus = esp_now_add_peer(&slave);
  if (addStatus == ESP_OK) {
    // Pair success
    Serial.println("Pair success");
  }
  // ESP-NOWコールバック登録
  esp_now_register_send_cb(OnDataSent);
  esp_now_register_recv_cb(OnDataRecv);

  //VL53
  Wire.begin(32, 33);  // join i2c bus (address optional for master)
}


void send_data(int num,int mode,int duty){
  uint8_t data[4] = {num,mode,0,duty};//num,mode,colormode,duty
    esp_err_t result = esp_now_send(slave.peer_addr, data, sizeof(data));
    Serial.print("Send Status: ");
    if (result == ESP_OK) {
      Serial.println("Success");
    } else if (result == ESP_ERR_ESPNOW_NOT_INIT) {
      Serial.println("ESPNOW not Init.");
    } else if (result == ESP_ERR_ESPNOW_ARG) {
      Serial.println("Invalid Argument");
    } else if (result == ESP_ERR_ESPNOW_INTERNAL) {
      Serial.println("Internal Error");
    } else if (result == ESP_ERR_ESPNOW_NO_MEM) {
      Serial.println("ESP_ERR_ESPNOW_NO_MEM");
    } else if (result == ESP_ERR_ESPNOW_NOT_FOUND) {
      Serial.println("Peer not found.");
    } else {
      Serial.println("Not sure what happened");
    }
    delay(30);

}

void StartSQ(int mode){
  SQmode = mode;
  SQstartTime = millis();
}
void EndSQ(){
  SQmode = 0 ;  
}
int checkSQ(){
  return SQmode;
}
void Sequence1(){
  int span =3000;
  int duty =120;
  int duty2 =150;
  int duty3 =200;
  int time = millis() - SQstartTime;
  if(time<span*1){
    send_data(1,2,duty);
    //Serial.print("1");
  }else if(span*1<=time && time<span*2){
    send_data(2,2,duty);
    //Serial.print("2");
  }
  else if(span*2<=time && time<span*3){
    send_data(3,2,duty);
    //Serial.print("3");
  }
  else if(span*3<=time && time<span*4){
    send_data(4,2,duty);
    //Serial.print("4");
  }
    else if(span*4<=time && time<span*5){
    send_data(5,2,duty);
  }
    else if(span*5<=time && time<span*6){
    send_data(1,2,duty2);
    send_data(2,2,duty2);
    send_data(3,2,duty2);
    send_data(4,2,duty2);
    send_data(5,2,duty2);
  }  else if(span*6<=time && time<span*7){
    send_data(1,2,duty3);
    send_data(2,2,duty3);
    send_data(3,2,duty3);
    send_data(4,2,duty3);
    send_data(5,2,duty3);
  }else if(span*7<=time){
    send_data(1,0,0);
    send_data(2,0,0);
    send_data(3,0,0);
    send_data(4,0,0);
    send_data(5,0,0);
    EndSQ();
    Serial.println("END_SQ");
  }

}
void Sequence2(){
  int time = millis() - SQstartTime;
  int span = 5000;
  int duty =0;
  if(time<span*1){
    send_data(1,0,duty);
    send_data(2,0,duty);
    send_data(3,0,duty);
    send_data(4,0,duty);
    send_data(5,0,duty);
  }else if(span*1<=time){
    EndSQ();
  }
}
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

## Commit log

2023-04-06 Revert "Initial commit"
    This reverts commit 64c8149a1abd8a3010d02ef33ff285a1a6623ebe.
    [configuration.h]
2023-04-06 MODE_A用inoを分離
2023-04-07 フォルダ構成変更
    [configuration.h]
2023-05-05 add FFT function
    [configuration.h]
2023-05-05 add case
2023-05-07 回転開始・脱調学習修正
    SPEED_CONTROLLER.inoをPHOTO.inoに統合
    MODE_STOP追加
    FFT修正
    ArduinoTrace追加(ライブラリ追加必要)
    [configuration.h]
2023-05-08 MODE_B(音量モード)追加
2023-06-05 INA219セットアップ削除
2023-09-08 add support for Uzurium Board v0.0.0
    [configuration.h]
2023-09-10 add serial plotter support
    [configuration.h]
2023-09-11 add stl
    [CAP2.stl, CASE_mae.stl, CASE_ushiro.stl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]
2023-09-11 add schematics
2023-09-27 Motor pin change
    [configuration.h]
2023-10-06 Update configuration.h
    add comment
    [configuration.h]
2023-10-06 Change MODE_A
    Rewrite MODE_A to a mode that directly reflects the AD value by the variable resistor to the motor DUTY.
2023-10-06 Update RINGLED.h
    change LED num and add counter(int)
2023-10-06 Update SW.ino
    Added long-press and double-click judgment for buttons
2023-10-06 Update Uzurium.ino
    Changed so that the operation mode can be selected at the touch of a button. Single press = any operation with rotation speed FB, Long press = motor drive by AD value, Double click = photo reflector 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
2023-10-28 BUZZER対応
2023-10-28 add PWM_Frequencies
2023-10-28 add UzuriumController
    [configuration.h]
2023-11-05 物理ボタン対応
2023-11-05 add PHOTO class
    [configuration.h]
2023-11-08 クラス化
    [configuration.h]
2023-11-08 add Mode
    Stop & ADinput MODE追加
    MODE classにactive変数追加
2023-11-14 add LED inspection Mode
2023-11-18 add SW class
    [configuration.h]
2023-11-18 add TimerMode
2023-11-28 Change Library from M5Unified to M5Atom
    [configuration.h]
2026-10-03 Add UzuriumCircuit_2 design files and reorganize hardware folder
    - Add Gerber, BOM, PCB layout PDF and DXF for UzuriumCircuit_2
    - Move schematics/ and stl/ under hardware/
    - Add README for each PCB folder (BOM table, rework notes)
    - Rewrite top-level README (repo layout, firmware targets, third-party notice)
    [3D_PCB_UzuriumCircuit_v.0.0.0.stl, BOM_UzuriumCircuit_UzuriumCircuit_2026-10-04.csv, CAP2.stl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]
